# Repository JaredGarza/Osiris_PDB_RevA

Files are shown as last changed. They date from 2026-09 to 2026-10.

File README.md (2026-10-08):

# Osiris PDB REV1.1 XT60 prototype

Updated October 8, 2026. J1 battery input and J3 ESC output now use AMASS XT60PW-F, matching J4. Finished board is 82.5 x 65.0 mm. The four mounting holes and remaining circuit placements are retained. Open Osiris_PDB_RevA.kicad_pro; keep Libraries and the library tables alongside the project.

**XT60PW-F is rated 45 A, with 60 A momentary and no stated duration. The previous 60 A continuous / 100 A for 30 s targets are not supported by this connector. A 5 A avionics allowance leaves a 40 A connector-based ESC ceiling; revised PCB ampacity is unqualified. F2 remains 100 A and does not establish overload protection of the 45 A connector.**

Four layers, 1.6 mm FR-4, ENIG, retained low-copper prototype choice of 1 oz outer / 0.5 oz inner. DRC, schematic parity and ERC passed with zero reported issues. These checks establish CAD consistency, not thermal/current capability.

Latest manufacturing files: [outputs/jlcpcb-rev1.1](outputs/jlcpcb-rev1.1). Upload Gerbers.zip intact for PCB fabrication, BOM.csv for assembly parts, and Pick_and_Place.csv for assembly placement. This folder contains only those three files. Verify exact manufacturer part matches and orientations in the factory preview; LCSC selections remain unconfirmed. The procurement workbook and grouped live calculation inputs are in [engineering](engineering). Earlier output packages should not be used for this board. No order was submitted.

The former 2.07 mOhm screening estimate applies only to the old copper geometry. The revised layout needs new resistance extraction or four-wire measurements, thermal qualification, transient measurements and fuse/harness/connector coordination. Protection corrections: D5 SMBJ18CA, C17 330 uF / 50 V EEHZL1H331P; retry is C3=100 nF (550 ms), gate ramp is C1=22 nF. Host I2C1 pull-ups R74/R75 are 4.7 kOhm. Use the three-wire data harness described in [HOST_INTERFACE.md](HOST_INTERFACE.md). A tested portable INA228 driver is in Firmware, pending target integration and physical verification. See [PROTECTION_FIX_STATUS.md](PROTECTION_FIX_STATUS.md) for unresolved pack interruption/startup/SOA items and the engineering workbook for formulas and input assumptions.

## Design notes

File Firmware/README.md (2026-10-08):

# PDB INA228 driver

This driver targets the PDB INA228 at 0x40, using its 5 mOhm avionics-only shunt. It does not measure ESC or whole-pack current. It is suitable for integration into Osiris STM32H743 I2C1; host wiring and resistors are documented in the package's HOST_INTERFACE.md. It is not an entire flight-controller firmware image, and has not been flashed or tested on physical hardware.

Supply callbacks with a finite timeout. At an STM32 HAL boundary, shift the 7-bit address left once. Register data is MSB first. Use 100 kHz initially; do not automatically fall back to a different bus or INA228 address.

Initialize `pdb_ina228` with the context, callbacks and measured shunt resistance, or nominal 0.005 Ohm for initial bring-up. Call `pdb_ina228_init` after the PDB local rail is present. It validates manufacturer/device IDs, selects ADCRANGE=0, programs SHUNT_CAL=4096, selects 16 averages and 1052 us V/I/temperature conversion times, and checks readback. Nominal CURRENT_LSB is 62.5 uA/count, with a signed positive span one count below 32.768 A. The analog high range is also 32.768 A nominal; the low 8.192 A range is inappropriate for the possible 12.12 A breaker corner. Readback after power loss is mandatory.

Poll roughly every 100 ms. `pdb_ina228_sample` returns a status and a `valid` flag. Never use a failed/not-ready sample as a zero-current reading. Invalid values are NaN. The driver detects I/O failures, changed/reset configuration, memory faults, arithmetic overflow and clipping. It performs signed 20-bit conversion and uses the integer calibration to calculate the actual LSB. Check the sample age in the application, and publish communication faults separately from electrical current. Power/energy/charge accumulation and an interrupt-based alert path are not implemented. Sequential reads are not an atomic multi-register snapshot.

After a configuration-loss/I/O failure, mark telemetry unavailable and retry initialization with a bounded application retry policy. A firmware reboot alone does not constitute a battery disconnect. This driver has no authority over motor throttles or power switches and cannot make the 60/100 A target compatible with the XT60 connectors. Automatic disarming or propulsion interruption requires integration with the existing flight application's safety behavior.

The supplied C unit test was compiled with MSVC `/W4 /WX /std:c11`; it checks positive/negative readings, clipping, sensor fault flags, wrong device, configuration loss, I/O failure and invalid shunt inputs. Physical bring-up and integration remain required.

Source: Texas Instruments [INA228 datasheet](https://www.ti.com/lit/ds/symlink/ina228.pdf), register map and calibration equations. Nominal board identity and connections come from the current PDB netlist.

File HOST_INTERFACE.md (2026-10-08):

# PDB REV1.1 to Osiris Rev B

Verified from the current OsirisRevA schematic/netlist, October 8, 2026. Host is STM32H743IIK6 U10; use I2C1, PB8 (SCL) / PB9 (SDA), initially 100 kHz. The PDB INA228 address is **0x40 (7 bit)**. Osiris's onboard INA228 IC11 is a different device on I2C4, address 0x4F; do not apply this PDB's 5 mOhm calibration to IC11.

| PDB J2 | Cable connection | Osiris J28 |
|---|---|---|
| Pin 1: INA_ALERT, open-drain | **No connection; omit this conductor** | Pin 1 is +5V0_PROT; leave unused |
| Pin 2: SCL | Connect | Pin 2: FMU_I2C1_SCL |
| Pin 3: SDA | Connect | Pin 3: FMU_I2C1_SDA |
| Pin 4: GND | Connect | Pin 4: GND |

**A straight four-wire cable is incompatible.** It applies host 5 V to PDB ALERT. Use a three-conductor cable in the four-position keyed housings, with cavity 1 empty at both ends. Poll the PDB instead of using ALERT in this connection. Inspect cavity numbering against both board footprints and perform cable continuity checks before connection. No 5 V supply is carried in this data cable.

PDB R17/R18 remain DNP. Osiris I2C1 R74/R75 were changed in the current host schematic and PCB from 12 kOhm to **4.7 kOhm**, 0402, Yageo RC0402FR-074K7L. They connect to the host's switched +3V3 rail. No other host I2C bus resistors were changed. Host production outputs were not regenerated as part of the PDB package; use Osiris_Host_Pullup_Changes.csv when rebuilding its BOM. Check that no connected peripheral adds an excessive parallel pull-up.

For 4.7 kOhm and the historical 90 pF assumption, tr = 0.8473 R C = 358.4 ns. At 100 kHz, the 1000 ns rise-time criterion implies about 251 pF total capacitance, before resistor tolerance and design margin. At 400 kHz, the 300 ns criterion implies about 75 pF, so **do not switch this harness to 400 kHz based on the 90 pF estimate**. Measure SCL/SDA rise time, low voltage and ringing on the installed harness. Keep the ground conductor alongside the data conductors.

The PDB ALERT buffer is not used by this polling cable. Do not connect host power to it. Verify the host-off/PDB-on and PDB-off/host-on cases on the assembled system. The INA228 SCL/SDA absolute rating is independent of VS, unlike its ALERT rating; this alone does not qualify the entire powered-off bus.

Power cable: **PDB J4 pin 2 (+PDB_VOUT) -> Osiris J17 pin 1 (+VBATT_OUT); PDB J4 pin 1 GND -> Osiris J17 pin 2 GND**. This supplies protected, unregulated 4S battery voltage. Connector pin numbers differ; never connect by pin number alone.

Firmware source is provided in `source_snapshot/Firmware`. It is a transport-independent driver, not a flashed or integrated Osiris application. Configure the actual STM32 clock-dependent timing value through the existing firmware project and connect finite-timeout read/write callbacks to I2C1. No runnable firmware project was found in the local Hardware/Osiris repositories.

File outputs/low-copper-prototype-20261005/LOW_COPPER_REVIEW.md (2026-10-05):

# Osiris PDB REV1.1 — Low Copper Prototype

Prepared October 5, 2026 from the current Osiris_PDB_RevA project.

**Selected prototype specification: 1 oz outer / 0.5 oz inner, four-layer FR-4, 1.6 mm total thickness. This is the lowest standard copper combination listed by JLCPCB, not a demonstrated minimum for the board's current targets. The 60 A continuous / 100 A for 30 seconds targets remain unqualified.**

Open `Osiris_PDB_RevA.kicad_pro`. This branch keeps the repository's original project filenames, with the revised low-copper PCB in place. Keep the local Libraries folder and library tables beside the project. The schematic and component placement remain the same as the source design. The bottom silkscreen identifies this board as `LC TEST 1/0.5oz`.

The input and ESC positive pours were widened on the top and supplemented with parallel bottom pours. The sharp top-zone step near J3 was removed. In1 remains an uninterrupted ground-plane zone; In2 now carries ground in its unused left, lower and right regions rather than filling those regions with positive copper. Added 22 vias: five distributed ESC ties, fourteen return-path ties and three local capacitor/test-point ground ties. Three short ground tracks connect the latter pads to their new vias. Existing routed tracks, vias, footprint positions, pad geometry and part selections were preserved.

All-severity PCB DRC, unconnected-item checks, schematic parity and schematic ERC passed with zero reported issues. Thirteen Gerber/drill files were independently parsed, and exported copper artwork was visually reviewed. The Gerber job specifies 35 / 17.5 / 17.5 / 35 µm copper. The generic dielectric entries maintain nominal 1.6 mm thickness; use the manufacturer's standard compatible stackup rather than treating those entries as a controlled dielectric requirement.

## Quotation files

Use `outputs/low-copper-prototype-20261005/Osiris_PDB_REV1.1_LowCopper_Prototype_Gerbers.zip` for PCB upload. The same directory contains the unchanged BOM/CPL, assembly instructions, fabrication notes and checks; start with `START_HERE.md`. Earlier manufacturing packages retained in this repository describe the original board and must not be used for this revision. Select **1 oz outer and 0.5 oz inner explicitly** on the quote page; Gerber artwork alone does not establish copper weight. No order has been placed, and no savings amount has been verified.

## Resistance screening and test limits

A nominal room-temperature DC grid model compared the original and widened layouts. It includes positive paths and the ESC ground return, sheet-copper conductance and nominal 25 µm plated via barrels. It assumes ideal connector terminals and excludes fuse/contact/solder resistance, enclosure behavior and thermal coupling. Pads were simplified to rectangles/circles. This is a screening model, not a certified field solver or thermal simulation.

| Layout | Outer / inner | Estimated copper loop resistance | Estimated copper-only loss at 60 A |
|---|---|---:|---:|
| Original | 2 / 2 oz | 0.83 mΩ | 3.0 W |
| Widened | 2 / 1 oz | 1.06 mΩ | 3.8 W |
| Widened | 2 / 0.5 oz | 1.34 mΩ | 4.8 W |
| **Selected lowest-copper prototype** | **1 / 0.5 oz** | **2.07 mΩ** | **7.5 W** |

The selected prototype's estimated copper loop resistance is approximately **2.5 times the original** despite widening. Its approximate copper-only drop is 124 mV at 60 A. These figures do not include the fuse's substantial additional loss, and copper resistance increases with temperature. A preliminary 0.25 mm grid and the final 0.20 mm grid gave similar loop estimates, but that numerical agreement does not validate the model assumptions. Raw results are in `outputs/low-copper-prototype-20261005/checks/dc-screen-0.2.json`; that file records the geometry hashes.

Load/temperature measurements are required before accepting this copper choice for the current targets. Test both positive and ground drop, fuse/connector/via-region temperatures, and avionics behavior in the actual enclosure and ambient conditions. Input current can reach 65 A continuous or 105 A burst with a simultaneous 5 A avionics load; the model table above considers the 60 A ESC loop alone. Establish component-based temperature limits and measure steady-state behavior before attempting the target burst. If the lowest-copper prototype fails those requirements, use the measured results to select a heavier build or revise the layout further. This review cannot establish the lowest electrically adequate copper weight without those results.

Manufacturer copper options: [JLCPCB copper-weight guide](https://jlcpcb.com/help/article/jlcpcb-copper-weight). Current availability and price depend on the selected manufacturing/assembly service.

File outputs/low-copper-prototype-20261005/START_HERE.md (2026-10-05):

# Osiris PDB REV1.1 Low Copper — test prototype package

Upload **Osiris_PDB_REV1.1_LowCopper_Prototype_Gerbers.zip** for PCB quotation. Use **JLCPCB_BOM.csv** and **JLCPCB_CPL.csv** for assembly quotation.

Select four layers, FR-4, 1.6 mm, **1 oz outer / 0.5 oz inner**, ENIG and the requested quantity. Finished outline is 127.5 × 65 mm. Confirm the selected copper combination and assembly/panel requirements with JLCPCB.

This revised board has wider top copper, added bottom power pours, revised In2 ground return and 22 new vias. Its schematic, components, footprints and placement are unchanged. Do not upload the earlier RevA Gerbers with this package.

**TEST PROTOTYPE ONLY:** the lowest standard copper option was selected at the user's request. It is not qualified for 60 A continuous / 100 A for 30 seconds. Estimated copper-loop resistance is about 2.5 times the original 2/2 oz board. See LOW_COPPER_REVIEW.md for the estimate and physical testing still needed.

The BOM contains 56 fitted parts in 41 groups. Exact manufacturer/MPN matching and every polarity/orientation require checking in JLCPCB's assembly preview. F1 is the holder; the removable 7.5 A fuse is supplied separately. R17/R18 are DNP. No order has been placed.

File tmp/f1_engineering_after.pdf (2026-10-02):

D1 | 1 | SMAJ24CA | Bidirectional 400 W TVS; 24 V standoff, 26.7 V min
| | | breakdown, 38.9 V clamp | Diode_SMD:D_SMA | Bourns | SMAJ24CA

Bidirectional 24 V TVS candidate; 38.9 V specified clamp is pulsecondition dependent. Source energy, ringing and downstream peak
voltage remain open. | Open datasheet
D3 | 1 | STPST10H100SB | 100V 10A | PDB_Footprints:STPST10H100SB_DPAK | STMicroelectronics | STPST10H100SB-TR

Selected power clamp. Connect both anode leads to GND and cathode
tab to PDB_VOUT. Pulse/thermal validation required. | Open datasheet
D4 | 1 | SMAJ24CA | Bidirectional 400 W TVS; 24 V standoff, 26.7 V min
| | | breakdown, 38.9 V clamp | Diode_SMD:D_SMA | Bourns | SMAJ24CA

Selected: local bidirectional clamp from IDEAL_IN to U5 reference
IDEAL_VSS. | Open datasheet
D5 | 1 | SMBJ24CA

Bidirectional 24 V TVS candidate for local ESC
connector ringing control; validate pulse energy
and clamp voltage on the installed harness. | Diode_SMD:D_SMB | Littelfuse | SMBJ24CA

Procurement selection: Littelfuse SMBJ24CA. Retained for local ringing control; validate installed harness pulse energy and clamp behavior.

F1 | 1 | 7.5A MINI

7.5 A, 32 VDC MINI blade fuse; backup protection
for a fault the MOSFETs cannot interrupt | Fuse:Fuseholder_Blade_Mini_Keystone_3568 | Littelfuse | 029707.5WXNV | Keystone Electronics 3568 | Open datasheet

7.5 A 32 V MINI selected for 5 A continuous avionics allowance (67% of
fuse rating). Electronic breaker remains nominally 10 A; fuse, source | Open datasheet
F2 | 1 | SCHURTER UHS 100A 3- 140-178 | 100 A surface-mount high-current fuse candidate for the dedicated ESC branch

PDB_Footprints:SCHURTER_UHS_8.4x9.4mm_PR
OVISIONAL | SCHURTER | 3-140-178

PROCUREMENT UPDATE: use 3-140-178 in place of original 3-140-177. SCHURTER lists identical 100 A / 50 V UHS electrical ratings and package dimensions; order-number difference is packaging. DigiKey offers 3-140-
178 cut tape. Engineering release checks still apply: verify 60 A
continuous temperature rise, 100 A/30 s time-current behavior, 4S
pack fault current, breaking capacity, and heavy-copper land pattern. | Open datasheet
H1 | 0 | MountingHole | Mounting Hole without connection

MountingHole:MountingHole_3.2mm_M3_ISO1 4580

H2 | 0 | MountingHole | Mounting Hole without connection

MountingHole:MountingHole_3.2mm_M3_ISO1 4580

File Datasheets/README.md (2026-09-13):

# Component datasheets

Downloaded PDFs are stored beside this index. `origin` in `sources.json` records
whether a PDF came from the manufacturer or a distributor mirror; mirrors were used
where the manufacturer host returned HTTP 403. Entries still marked as unavailable
keep a manufacturer link in the schematic instead.

| Document | Local file / status | Source |
|---|---|---|
| AMASS_XT60PW-F.pdf | [AMASS_XT60PW-F.pdf](AMASS_XT60PW-F.pdf) | [Source](https://www.tme.eu/Document/1191bc2fa3aee3c446e5a895fd8f7983/XT60PW-F.pdf) |
| AMASS_XT60PW-M.pdf | [AMASS_XT60PW-M.pdf](AMASS_XT60PW-M.pdf) | [Source](https://www.tme.eu/Document/b13629717d44ae038681dba08d18c0b6/XT60PW-M.pdf) |
| Bourns_SMAJ_TVS.pdf | [Bourns_SMAJ_TVS.pdf](Bourns_SMAJ_TVS.pdf) | [Source](https://www.bourns.com/docs/product-datasheets/smaj.pdf) |
| INA228.pdf | [INA228.pdf](INA228.pdf) | [Source](https://www.ti.com/lit/ds/symlink/ina228.pdf) |
| JST_GH.pdf | [JST_GH.pdf](JST_GH.pdf) | [Source](https://www.jst-mfg.com/product/pdf/eng/eGH.pdf) |
| KEMET_C0603C104K4RACTU.pdf | [KEMET_C0603C104K4RACTU.pdf](KEMET_C0603C104K4RACTU.pdf) | [Source](https://search.kemet.com/component-documentation/download/specsheet/C0603C104K4RACTU) |
| Keystone_3568.pdf | [Keystone_3568.pdf](Keystone_3568.pdf) | [Source](https://www.keyelco.com/product-pdf.cfm?p=306) |
| Keystone_catalog.pdf | [Keystone_catalog.pdf](Keystone_catalog.pdf) | [Source](https://www.keystone-europe.com/wp-content/uploads/catalog-keystone-europe.pdf) |
| Littelfuse_297_MINI.pdf | [Littelfuse_297_MINI.pdf](Littelfuse_297_MINI.pdf) (mirror) | [Source](https://www.ficcorp.com/content/297-datasheet.pdf) |
| Littelfuse_MINI_0297.pdf | Superseded by Littelfuse_297_MINI.pdf | [Source](https://www.littelfuse.com/assetdocs/littelfuse_datasheet_297_mini32v.pdf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) |
| Littelfuse_MINI_0297_selection_guide.pdf | Superseded by Littelfuse_297_MINI.pdf | [Source](https://www.littelfuse.com/assetdocs/fuse-selection-guide?assetguid=1d99e3a6-f314-48d7-b124-9d5d56955f09) |
| Nexperia_74AUP1G07.pdf | [Nexperia_74AUP1G07.pdf](Nexperia_74AUP1G07.pdf) | [Source](https://assets.nexperia.com/documents/data-sheet/74AUP1G07.pdf) |
| Ohmite_FC4L.pdf | [Ohmite_FC4L.pdf](Ohmite_FC4L.pdf) (mirror) | [Source](https://www.tti.com/content/dam/ttiinc/manufacturers/ohmite/doc/ohmite-fc4l-series-current-sense-resistors-datasheet-and-specifications.pdf) |
| TDK_C1608X7R1H104K080AA.pdf | Online link; PDF download unavailable | [Source](https://product.tdk.com/info/en/documents/chara_sheet/C1608X7R1H104K080AA.pdf) |
| TDK_C2012C0G2A562J125AA.pdf | Online link; PDF download unavailable | [Source](https://product.tdk.com/info/en/documents/chara_sheet/C2012C0G2A562J125AA.pdf) |
| TDK_C2012X7R1A106K125AC.pdf | Online link; PDF download unavailable | [Source](https://product.tdk.com/info/en/documents/chara_sheet/C2012X7R1A106K125AC.pdf) |
| TDK_C2012X7R1H105K125AB.pdf | Online link; PDF download unavailable | [Source](https://product.tdk.com/info/en/documents/chara_sheet/C2012X7R1H105K125AB.pdf) |
| TDK_C3216X7R1H106K160AC.pdf | Online link; PDF download unavailable | [Source](https://product.tdk.com/info/en/documents/chara_sheet/C3216X7R1H106K160AC.pdf) |
| TPS7A16.pdf | [TPS7A16.pdf](TPS7A16.pdf) | [Source](https://www.ti.com/lit/ds/symlink/tps7a16.pdf) |
| onsemi_MBR0540.pdf | [onsemi_MBR0540.pdf](onsemi_MBR0540.pdf) (mirror) | [Source](https://cdn-reichelt.de/documents/datenblatt/A400/MBR0540T1-D.PDF) |

Existing project PDFs: [LTC4368](LTC4368%20%28Rev%20C%29.pdf) and [ISC015N06NM5LF2](Datasheet%20ISC015N06NM5LF2.pdf).

TDK links refer to characteristic sheets; the schematic retains manufacturer
product pages for each selected capacitor.

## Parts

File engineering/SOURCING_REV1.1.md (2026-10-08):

# REV1.1 procurement substitutions

Checked October 8, 2026. Updated 14 fitted components across 11 MPN groups. Values, packages, copper routing and board size are unchanged. Resistors are 0805, 1%, 125 mW, 150 V; 10 ohm parts have 200 ppm/K TCR and the others 100 ppm/K. Capacitors are 0805, X7R, 50 V, 10%. Stock is a reported snapshot, not a guarantee of future availability or JLC assembly stock. Confirm exact parts at order time.

| References | Selected MPN | LCSC | Reported stock |
|---|---|---|---:|
| C2,C18 | CC0805KKX7R9BB105 | [C91185](https://www.lcsc.com/product-detail/C91185.html) | 767,960 |
| C19 | CC0805KRX7R9BB104 | [C49678](https://www.lcsc.com/product-detail/C49678.html) | 8,362,320 |
| R3 | 0805W8F2004T5E | [C26112](https://www.lcsc.com/product-detail/C26112.html) | 17,200 |
| R4 | 0805W8F2202T5E | [C17560](https://www.lcsc.com/product-detail/C17560.html) | 1,226,000 |
| R6 | 0805W8F6803T5E | [C17797](https://www.lcsc.com/product-detail/C17797.html) | 64,300 |
| R7 | 0805W8F2003T5E | [C17539](https://www.lcsc.com/product-detail/C17539.html) | 428,200 |
| R8,R9 | 0805W8F100JT5E | [C17415](https://www.lcsc.com/product-detail/C17415.html) | 4,712,400 |
| R10 | 0805W8F4701T5E | [C17673](https://www.lcsc.com/product-detail/C17673.html) | 1,678,600 |
| R12 | 0805W8F1001T5E | [C17513](https://www.lcsc.com/product-detail/C17513.html) | 24,259,800 |
| R15,R16 | 0805W8F1002T5E | [C17414](https://www.lcsc.com/product-detail/C17414.html) | 48,598,900 |
| R21 | 0805W8F1000T5E | [C17408](https://www.lcsc.com/product-detail/C17408.html) | 6,871,100 |

C17 remains Panasonic EEHZL1H331P: 330 µF, 50 V, 12 mΩ at 100 kHz and 5 A ripple at 125 °C. No verified single-part replacement was found meeting capacitance, voltage, ESR, ripple current and the G16 package. EEH-ZU1H221P is only 220 µF and is not an approved direct replacement. Two parallel parts would require a separate layout and transient validation.

Retained the linear-mode MOSFETs, protection ICs, INA228, Kelvin shunt, high-power resistors, fuses and film capacitors because a sourcing swap must preserve their specific electrical function. Existing KEMET 0603 decouplers already have deep reported stock; the investigated Samsung option had much less reported stock. Precision divider values were retained.

Fresh KiCad DRC: zero violations, zero unconnected items, zero schematic parity issues. ERC: zero violations. Calculation inputs and formulas are unchanged. These CAD checks do not establish hardware transient or thermal qualification.

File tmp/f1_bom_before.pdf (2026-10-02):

Boards to build | 5 | Estimated cost / board
Category | References | Value / Part | Manufacturer
Capacitor | C1 | 22n | TDK
Capacitor | C2 | 1U0 | TDK
Capacitor | C3, C5, C8, C10 | 100n | KEMET
Capacitor | C4, C9 | 10u | TDK
Capacitor | C6 | 10u | TDK
Capacitor | C7 | 100n | TDK
Capacitor | C11, C12, C13, C14, C15, C16 1u | TDK
Capacitor | C17 | 470u 35V HYBRID | Panasonic
Capacitor | C18 | 1u 50V X7R | KYOCERA AVX
Capacitor | C19 | 100n 50V X7R | KEMET
Diode / TVS | D1, D4 | SMAJ24CA | Bourns
Diode / TVS | D3 | STPST10H100SB | STMicroelectronics
Diode / TVS | D5 | SMBJ24CA | Littelfuse
Fuse | F1 | 4A MINI | Littelfuse
Fuse | F2 | SCHURTER UHS 100A 3-140-
| | 178 | SCHURTER
Connector | J1, J3 | MKDSP 25/2-15.00
| | PROVISIONAL | Phoenix Contact
Connector | J2 | OSIRIS_I2C | JST

## Osiris PDB Rev A — Purchasing BOM (links corrected)

Updated from the Oct. 1, 2026 KiCad design and purchasing sheet. Existing priced rows remain legacy budget values unless marked otherwise; shipping/tax/assembly excluded.

Connector | J4 | XT60PW-F | AMASS
MOSFET | Q1, Q2 | ISC015N06NM5LF2 | Infineon
MOSFET | Q3 | BSC070N10NS5 | Infineon
Resistor | R1 | 237k | YAGEO
Resistor | R2 | 11k8 | YAGEO
Resistor | R3 | 2M0 | YAGEO
Resistor | R4 | 22k | YAGEO
Resistor | R5 | 5m | Ohmite
Resistor | R6 | 680k | YAGEO
Resistor | R7 | 200k | YAGEO
Resistor | R8, R9 | 10 | YAGEO
Resistor | R10, R17 (DNP), R18 (DNP) | 4k7 | YAGEO
Resistor | R11 | 1k58 | YAGEO
Resistor | R12 | 1k0 | YAGEO
Resistor | R13 | 54k9 | YAGEO
Resistor | R14 | 22M | YAGEO
Resistor | R15, R16 | 10k | YAGEO
Resistor | R19 | 1k | Vishay
Resistor | R20 | 1 | Vishay
Resistor | R21 | 100 | Yageo
IC | U1 | LTC4368HMS-1-PBF | Analog Devices

IC | U2 | INA228AIDGSR | Texas Instruments
IC | U3 | LT3010EMS8E | Analog Devices
IC | U4 | 74AUP1G07GW | Nexperia
IC | U5 | LTC4359IMS8 | Analog Devices
Fuse Holder | F1-holder | MINI fuse holder | Keystone Electronics
ESTIMATED TOTAL (all unit prices filled; F2 currently stock-blocked)

87.2124 Estimated batch cost 436.062

Manufacturer P/N | Qty / Board Board Count (X) | Total Qty | Unit Cost (USD)
C2012C0G2A223J125AC | 1 | 5 | 5 | $0.30
C2012X7R1H105K125AB | 1 | 5 | 5 | $0.26
C0603C104K4RACTU | 4 | 5 | 20 | $0.13
C3216X7R1H106K160AC | 2 | 5 | 10 | $0.98
C2012X7R1A106K125AC | 1 | 5 | 5 | $0.33
C1608X7R1H104K080AA | 1 | 5 | 5 | $0.10
B32529C0105J189 | 6 | 5 | 30 | $0.30
EEH-ZS1V471P | 1 | 5 | 5 | $2.78
08055C105KAT2A | 1 | 5 | 5 | $0.27
C0805C104K5RACTU | 1 | 5 | 5 | $0.18
SMAJ24CA | 2 | 5 | 10 | $0.53
STPST10H100SB-TR | 1 | 5 | 5 | $1.44
SMBJ24CA | 1 | 5 | 5 | $0.57
0297004.WXNV | 1 | 5 | 5 | $0.39
3-140-178 | 1 | 5 | 5 | $1.07
1932588 | 2 | 5 | 10 | $13.01
BM04B-GHS-TBT(LF)(SN) | 1 | 5 | 5 | $0.38

XT60PW-F | 1 | 5 | 5 | $0.65
ISC015N06NM5LF2ATMA1 | 2 | 5 | 10 | $4.07
BSC070N10NS5ATMA1 | 1 | 5 | 5 | $2.24
RC0805FR-07237KL | 1 | 5 | 5 | $0.10
RC0805FR-0711K8L | 1 | 5 | 5 | $0.10
RC0805FR-072ML | 1 | 5 | 5 | $0.10
RC0805FR-0722KL | 1 | 5 | 5 | $0.10
FC4L64R005FER | 1 | 5 | 5 | $2.69
RC0805FR-07680KL | 1 | 5 | 5 | $0.10
RC0805FR-07200KL | 1 | 5 | 5 | $0.10
RC0805FR-0710RL | 2 | 5 | 10 | $0.12
RC0805FR-074K7L | 1 | 5 | 5 | $0.10
RC0805FR-071K58L | 1 | 5 | 5 | $0.10
RC0805FR-071KL | 1 | 5 | 5 | $0.10
RC0805FR-0754K9L | 1 | 5 | 5 | $0.10
RC0805JR-0722ML | 1 | 5 | 5 | $0.16
RC0805FR-0710KL | 2 | 5 | 10 | $0.10
CRCW25121K00FKEGHP | 1 | 5 | 5 | $0.75
CRCW25121R00FKEGHP | 1 | 5 | 5 | $0.96
RC0805FR-07100RL | 1 | 5 | 5 | $0.10
LTC4368HMS-1#TRPBF | 1 | 5 | 5 | $9.32

INA228AIDGSR

1

5

5 | $4.68

LT3010EMS8E#TRPBF

1

5

5 | $6.45

74AUP1G07GW,125

1

5

5 | $0.19

LTC4359IMS8#TRPBF

1

5

5 | $8.72

3568

1

5

5 | $1.31

Availability blockers | 0 | Resolved link/MPN gaps
Cost / Board | Total Cost | Distributor | Buy Link
$0.30 | $1.50 DigiKey | Supplier page
$0.26 | $1.30 DigiKey | Supplier page
$0.52 | $2.60 DigiKey | Supplier page
$1.96 | $9.80 DigiKey | Supplier page
$0.33 | $1.65 DigiKey | Supplier page
$0.10 | $0.50 DigiKey | Supplier page
$1.78 | $8.91 Mouser | Buy
$2.78 | $13.90 DigiKey | Buy
$0.27 | $1.35 DigiKey | Buy
$0.18 | $0.90 DigiKey | Buy
$1.06 | $5.30 Mouser | Supplier page
$1.44 | $7.20 DigiKey | Buy
$0.57 | $2.85 DigiKey | Buy
$0.39 | $1.95 Mouser | Supplier page
$1.07 | $5.37 DigiKey | Buy
$26.02 | $130.10 Mouser | Buy
$0.38 | $1.90 Mouser | Supplier page

$0.65 | $3.23 LCSC | Buy
$8.14 | $40.70 DigiKey | Supplier page
$2.24 | $11.20 Mouser | Buy
$0.10 | $0.50 DigiKey | Supplier page
$0.10 | $0.50 DigiKey | Supplier page
$0.10 | $0.50 Mouser | Supplier page
$0.10 | $0.50 DigiKey | Supplier page
$2.69 | $13.45 Mouser | Supplier page
$0.10 | $0.50 Mouser | Supplier page
$0.10 | $0.50 Mouser | Supplier page
$0.24 | $1.20 DigiKey | Supplier page
$0.10 | $0.50 DigiKey | Supplier page
$0.10 | $0.50 DigiKey | Supplier page
$0.10 | $0.50 DigiKey | Supplier page
$0.10 | $0.50 DigiKey | Supplier page
$0.16 | $0.80 DigiKey | Supplier page
$0.20 | $1.00 DigiKey | Supplier page
$0.75 | $3.75 Mouser | Buy
$0.96 | $4.80 DigiKey | Buy
$0.10 | $0.50 DigiKey | Buy
$9.32 | $46.60 Mouser | Buy

$4.68 | $23.40 DigiKey | Supplier page
$6.45 | $32.25 DigiKey | Supplier page
$0.19 | $0.95 DigiKey | Supplier page
$8.72 | $43.60 Mouser | Buy
$1.31 | $6.55 DigiKey | Supplier page
$87.21 | $436.06

15

Source URL

https://www.digikey.com/en/products/detail/tdkcorporation/C2012C0G2A223J125AC/5023347https://www.digikey.com/en/products/detail/tdk/C2012X7R1H105K125AB/2732982
https://www.digikey.com/en/products/detail/kemet/C0603C104K4RACTU/411095
https://www.digikey.com/en/products/detail/tdk/C3216X7R1H106K160AC/9991386
https://www.digikey.com/en/products/detail/tdkcorporation/C2012X7R1A106K125AC/2619198https://www.digikey.com/en/products/detail/tdk/C1608X7R1H104K080AA/513811
https://www.mouser.com/ProductDetail/TDK/B32529C0105J189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
https://www.mouser.com/en/ProductDetail/Bourns/SMAJ24CA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

https://www.mouser.com/ProductDetail/Littelfuse/0297004.WXNV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
https://www.mouser.com/en/ProductDetail/Phoenix-Contact/1932588?qs=zGjMOL9s0Z%252BnZxcpLOCAEA %3D%3D
https://www.mouser.com/ProductDetail/JST-Commercial/BM04B-GHS-TBTLFSNhttps://lcsc.com/product-detail/plug_changzhou-amasselec-xt60pw-f_C428722.htmlhttps://www.digike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

https://www.mouser.com/en/ProductDetail/Infineon-Technologies/BSC070N10NS5ATMA1?qs=3Bi3m9r5MQY NTOsczKwccQ%3D%3D
https://www.digikey.com/en/products/detail/yageo/RC0805FR-07237KL/727754
https://www.digikey.com/en/products/detail/yageo/RC0805FR-0711K8L/730505
https://www.mouser.com/ProductDetail/YAGEO/RC080 5FR-072ML
https://www.digikey.com/en/products/detail/yageo/RC0805FR-0722KL/730683
https://www.mouser.com/ProductDetail/Ohmite/FC4L6 4R005FER
https://www.mouser.com/ProductDetail/YAGEO/RC080 5FR-07680KL
https://www.mouser.com/en/ProductDetail/YAGEO/RC 0805FR-07200KL
https://www.digikey.com/en/products/detail/yageo/RC0805FR-0710RL/730481
https://www.digikey.com/en/products/detail/yageo/RC0805FR-074K7L/727929
https://www.digikey.com/en/products/detail/yageo/RC0805FR-071K58L/730449
https://www.digikey.com/en/products/detail/yageo/RC0805FR-071KL/727444
https://www.digikey.com/en/products/detail/yageo/RC0805FR-0754K9L/728029
https://www.digikey.com/en/products/detail/yageo/RC0805JR-0722ML/5919060
https://www.digikey.com/en/products/detail/yageo/RC0805FR-0710KL/727535
https://www.mouser.com/en/ProductDetail/Vishay/CRCW25121K00FKEGHP?qs=FlFvgi4rxBxxON%252BaL1o0tw %3D%3D
https://www.digikey.com/en/products/detail/vishaydale/CRCW25121R00FKEGHP/2222582https://www.digikey.com/en/products/detail/yageo/RC0805FR-07100RL/727543
https://www.mouser.com/ProductDetail/Analog-Devices/LTC4368HMS-1TRPBF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 BvsYg%3D%3D
https://www.digikey.com/en/products/detail/keystoneelectronics/3568/2137306

Reference | Quantity | Value | Specification
C1 | 1 | 22n | 100V C0G 5%
C2 | 1 | 1U0 | 50V X7R
C3 | 1 | 100n | 16V X7R
C4 | 1 | 10u | 50V X7R
C5 | 1 | 100n | 16V X7R
C6 | 1 | 10u | 10V X7R
C7 | 1 | 100n | 50V X7R
C8 | 1 | 100n | 16V X7R
C9 | 1 | 10u | 50V X7R
C10 | 1 | 100n | 16V X7R; LT3010 feedback compensation
C11 | 1 | 1u | 63V film 5%
C12 | 1 | 1u | 63V film 5%
C13 | 1 | 1u | 63V film 5%
C14 | 1 | 1u | 63V film 5%
C15 | 1 | 1u | 63V film 5%
C16 | 1 | 1u | 63V film 5%

## Osiris PDB Rev A — Engineering BOM Detail

Cross-checked against the uploaded current KiCad schematic. C17 and R19 metadata were stale in the purchasing workbook; C18/C19/D5 procurement selections are recorded here.

C17 | 1 | 470u 35V HYBRID | Local supplemental ESC capacitor: 470 uF, 35 V hybrid, 11 mOhm ESR at 100 kHz, 4 Arms at 100 kHz/125 C. Preserve the ESC manufacturer-required capacitor at the ESC.
C18 | 1 | 1u 50V X7R | 50 V X7R ceramic bypass for the ESC branch
C19 | 1 | 100n 50V X7R | 50 V X7R high-frequency bypass for the ESC branch
D1 | 1 | SMAJ24CA | Bidirectional 400 W TVS; 24 V standoff, 26.7 V min breakdown, 38.9 V clamp
D3 | 1 | STPST10H100SB | 100V 10A
D4 | 1 | SMAJ24CA | Bidirectional 400 W TVS; 24 V standoff, 26.7 V min breakdown, 38.9 V clamp
D5 | 1 | SMBJ24CA

Bidirectional 24 V TVS candidate for local ESC connector ringing control; validate pulse energy and clamp voltage on the installed harness.

F1 | 1 | 4A MINI

4 A, 32 VDC MINI blade fuse; backup protection for a fault the MOSFETs cannot interrupt

F2 | 1 | SCHURTER UHS 100A 3- 140-178 | 100 A surface-mount high-current fuse candidate for the dedicated ESC branch
H1 | 0 | MountingHole | Mounting Hole without connection
H2 | 0 | MountingHole | Mounting Hole without connection
H3 | 0 | MountingHole | Mounting Hole without connection
H4 | 0 | MountingHole | Mounting Hole without connection
J1 | 1

MKDSP 25/2-15.00
PROVISIONAL

4S battery input; pin 1 GND, pin 2 VBAT_RAW. Phoenix Contact 1932588 terminal; footprint and assembly require verification.

J2 | 1 | OSIRIS_I2C

JST GH 4-way I2C: 1 NC, 2 SCL, 3 SDA, 4 GND. New Osiris interface and cable continuity require verification.

J3 | 1

MKDSP 25/2-15.00
PROVISIONAL

Dedicated ESC output after F2; pin 1 GND, pin 2 ESC_VBAT. Phoenix Contact 1932588 terminal; footprint and assembly require verification.

J4 | 1 | XT60PW-F

Avionics raw-4S output to Osiris: pin 1 GND, pin 2 PDB_VOUT. This connector remains on the protected 4 A avionics branch.

Q1 | 1 | ISC015N06NM5LF2

Insulated-Gate Field-Effect Transistor (IGFET), N-Channel, Enhancement, Body Diode, Pin 1 Source, 2 Source, 3 Source, 4 Gate, 5 Drain, 6 Drain, 7 Drain, 8 Drain, 8 Pins
Q2 | 1 | ISC015N06NM5LF2 | Insulated-Gate Field-Effect Transistor (IGFET), N-
| | | Channel, Enhancement, Body Diode, Pin 1 Source, 2
| | | Source, 3 Source, 4 Gate, 5 Drain, 6 Drain, 7 Drain,
| | | 8 Drain, 8 Pins
Q3 | 1 | BSC070N10NS5 | 100V ideal diode MOSFET
R1 | 1 | 237k | Resistor
R2 | 1 | 11k8 | Resistor
R3 | 1 | 2M0 | Resistor
R4 | 1 | 22k | Series resistor in gate-to-ground timing branch
R5 | 1 | 5m | 1% 2W
R6 | 1 | 680k | Resistor
R7 | 1 | 200k | Resistor
R8 | 1 | 10 | Resistor
R9 | 1 | 10 | Resistor
R10 | 1 | 4k7 | Resistor
R11 | 1 | 1k58 | 1% 0.125W; upper feedback resistor
R12 | 1 | 1k0 | 1% 0.125W; lower feedback resistor
R13 | 1 | 54k9 | Resistor
R14 | 1 | 22M | Resistor
R15 | 1 | 10k | Resistor
R16 | 1 | 10k | Resistor
R17 | 0 | 4k7 | Optional SCL pull-up; do not populate
R18 | 0 | 4k7 | Optional SDA pull-up; do not populate
R19 | 1 | 1k | Pulse-rated
R20 | 1 | 1 | Pulse-rated
R21 | 1 | 100 | 1%
TP1 | 0 | TestPoint | test point
TP2 | 0 | TestPoint | test point
TP3 | 0 | TestPoint | test point

TP4 | 0 | TestPoint | test point
TP5 | 0 | TestPoint | test point
TP6 | 0 | TestPoint | test point
TP7 | 0 | TestPoint | test point
U1 | 1 | LTC4368HMS-1-PBF

Approved H-temperature-grade LTC4368-1; pin/function-compatible with LTC4368IMS-1 and rated -40 C to 125 C
U2 | 1 | INA228AIDGSR
U3 | 1 | LT3010EMS8E | Reverse-protected local 3.3 V supply
U4 | 1 | 74AUP1G07GW | Single Buffer Gate, Open Drain, Low-Voltage CMOS
U5 | 1 | LTC4359IMS8 | Reverse-current blocker
F1-holder | 1 | MINI fuse holder | Separate purchased holder for F1

Footprint | Manufacturer | MPN
Capacitor_SMD:C_0805_2012Metric | TDK | C2012C0G2A223J125AC
Capacitor_SMD:C_0805_2012Metric | TDK | C2012X7R1H105K125AB
Capacitor_SMD:C_0603_1608Metric | KEMET | C0603C104K4RACTU
Capacitor_SMD:C_1206_3216Metric | TDK | C3216X7R1H106K160AC
Capacitor_SMD:C_0603_1608Metric | KEMET | C0603C104K4RACTU
Capacitor_SMD:C_0805_2012Metric | TDK | C2012X7R1A106K125AC
Capacitor_SMD:C_0603_1608Metric | TDK | C1608X7R1H104K080AA
Capacitor_SMD:C_0603_1608Metric | KEMET | C0603C104K4RACTU
Capacitor_SMD:C_1206_3216Metric | TDK | C3216X7R1H106K160AC
Capacitor_SMD:C_0603_1608Metric | KEMET | C0603C104K4RACTU

Capacitor_THT:C_Rect_L7.2mm_W4.5mm_P5.00
mm | TDK | B32529C0105J189

Capacitor_THT:C_Rect_L7.2mm_W4.5mm_P5.00
mm | TDK | B32529C0105J189

Capacitor_THT:C_Rect_L7.2mm_W4.5mm_P5.00
mm | TDK | B32529C0105J189

Capacitor_THT:C_Rect_L7.2mm_W4.5mm_P5.00
mm | TDK | B32529C0105J189

Capacitor_THT:C_Rect_L7.2mm_W4.5mm_P5.00
mm | TDK | B32529C0105J189

Capacitor_THT:C_Rect_L7.2mm_W4.5mm_P5.00
mm | TDK | B32529C0105J189

PDB_Footprints:CP_Elec_Panasonic_G16_10x16.
5 | Panasonic | EEH-ZS1V471P
Capacitor_SMD:C_0805_2012Metric | KYOCERA AVX | 08055C105KAT2A
Capacitor_SMD:C_0805_2012Metric | KEMET | C0805C104K5RACTU
Diode_SMD:D_SMA | Bourns | SMAJ24CA
PDB_Footprints:STPST10H100SB_DPAK | STMicroelectronics | STPST10H100SB-TR
Diode_SMD:D_SMA | Bourns | SMAJ24CA
Diode_SMD:D_SMB | Littelfuse | SMBJ24CA
Fuse:Fuseholder_Blade_Mini_Keystone_3568 | Littelfuse | 0297004.WXNV

PDB_Footprints:SCHURTER_UHS_8.4x9.4mm_PR
OVISIONAL | SCHURTER | 3-140-178
MountingHole:MountingHole_3.2mm_M3_ISO1
4580
MountingHole:MountingHole_3.2mm_M3_ISO1
4580
MountingHole:MountingHole_3.2mm_M3_ISO1 4580
MountingHole:MountingHole_3.2mm_M3_ISO1 4580

PDB_Footprints:MKDSP25_2_15mm_PROVISION
AL | Phoenix Contact | 1932588

Connector_JST:JST_GH_BM04B-GHS-TBT_1x04-
1MP_P1.25mm_Vertical | JST | BM04B-GHS-TBT(LF)(SN)

PDB_Footprints:MKDSP25_2_15mm_PROVISION
AL | Phoenix Contact | 1932588

Connector_AMASS:AMASS_XT60PW-
F_1x02_P7.20mm_Horizontal | AMASS | XT60PW-F

PDB_Footprints:ISC015N06NM5LF2_TDSON8FL Infineon | ISC015N06NM5LF2ATMA1
PDB_Footprints:ISC015N06NM5LF2_TDSON8FL Infineon | ISC015N06NM5LF2ATMA1
PDB_Footprints:BSC070N10NS5_TDSON8 | Infineon | BSC070N10NS5ATMA1
Resistor_SMD:R_0805_2012Metric | YAGEO | RC0805FR-07237KL
Resistor_SMD:R_0805_2012Metric | YAGEO | RC0805FR-0711K8L
Resistor_SMD:R_0805_2012Metric | YAGEO | RC0805FR-072ML
Resistor_SMD:R_0805_2012Metric | YAGEO | RC0805FR-0722KL
PDB_Footprints:OH_FC4L64_OHM | Ohmite | FC4L64R005FER
Resistor_SMD:R_0805_2012Metric | YAGEO | RC0805FR-07680KL
Resistor_SMD:R_0805_2012Metric | YAGEO | RC0805FR-07200KL
Resistor_SMD:R_0805_2012Metric | YAGEO | RC0805FR-0710RL
Resistor_SMD:R_0805_2012Metric | YAGEO | RC0805FR-0710RL
Resistor_SMD:R_0805_2012Metric | YAGEO | RC0805FR-074K7L
Resistor_SMD:R_0805_2012Metric | YAGEO | RC0805FR-071K58L
Resistor_SMD:R_0805_2012Metric | YAGEO | RC0805FR-071KL
Resistor_SMD:R_0805_2012Metric | YAGEO | RC0805FR-0754K9L
Resistor_SMD:R_0805_2012Metric | YAGEO | RC0805JR-0722ML
Resistor_SMD:R_0805_2012Metric | YAGEO | RC0805FR-0710KL
Resistor_SMD:R_0805_2012Metric | YAGEO | RC0805FR-0710KL
Resistor_SMD:R_0805_2012Metric | YAGEO | RC0805FR-074K7L
Resistor_SMD:R_0805_2012Metric | YAGEO | RC0805FR-074K7L
Resistor_SMD:R_2512_6332Metric | Vishay | CRCW25121K00FKEGHP
Resistor_SMD:R_2512_6332Metric | Vishay | CRCW25121R00FKEGHP
Resistor_SMD:R_0805_2012Metric | Yageo | RC0805FR-07100RL
TestPoint:TestPoint_Pad_D1.5mm
TestPoint:TestPoint_Pad_D1.5mm
TestPoint:TestPoint_Pad_D1.5mm

TestPoint:TestPoint_Pad_D1.5mm TestPoint:TestPoint_Pad_D1.5mm TestPoint:TestPoint_Pad_D1.5mm TestPoint:TestPoint_Pad_D1.5mm

PDB_Footprints:MS_10-MSOP_ADI | Analog Devices | LTC4368HMS-1#TRPBF
PDB_Footprints:VSSOP10_DGS_TEX | Texas Instruments | INA228AIDGSR

Package_SO:MSOP-8-
1EP_3x3mm_P0.65mm_EP1.68x1.88mm | Analog Devices | LT3010EMS8E#TRPBF
Package_TO_SOT_SMD:SOT-353_SC-70-5 | Nexperia | 74AUP1G07GW,125
Package_SO:MSOP-8_3x3mm_P0.65mm | Analog Devices | LTC4359IMS8#TRPBF
Fuse:Fuseholder_Blade_Mini_Keystone_3568 | Keystone Electronics 3568

Holder Manufacturer | Holder MPN | Holder Datasheet

Keystone Electronics 3568 | Open datasheet

Selection Status | Datasheet

22 nF 5% C0G in series with R4 from GATE_PIN to GND. PDB-only
candidate; original Osiris eFuse configuration retained. | Open datasheet
Nominal specification verified; DC-bias and circuit validation pending | Open datasheet
Nominal specification verified; DC-bias and circuit validation pending | Open datasheet
10 uF local U3 input capacitor on protected PDB_VOUT. | Open datasheet
Nominal specification verified; DC-bias and circuit validation pending | Open datasheet
A-P2 LT3010 output capacitor: require >=1 uF effective over
bias/temperature and ESR <=3 ohms. Confirm manufacturer bias curve
and assembled stability. | Open datasheet
Nominal specification verified; DC-bias and circuit validation pending | Open datasheet
Nominal specification verified; DC-bias and circuit validation pending | Open datasheet
Output bulk capacitor; final total downstream capacitance and startup
load must meet the proposed September 15 envelope. Inrush not
qualified. | Open datasheet
A-P2 U3 feedback network; layout and assembled transient verification
required. | Open datasheet

Selected: 1 uF 63 V 5% polyester film. SPICE uses 0.9 uF minimum
effective capacitance; verify mounted pulse and temperature behavior. Open datasheet

Selected: 1 uF 63 V 5% polyester film. SPICE uses 0.9 uF minimum
effective capacitance; verify mounted pulse and temperature behavior. Open datasheet

Selected: 1 uF 63 V 5% polyester film. SPICE uses 0.9 uF minimum
effective capacitance; verify mounted pulse and temperature behavior. Open datasheet

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

Selected EEH-ZS1V471P G16; 10 mm diameter, 16.5/16.8 mm class height. Additional ESC-side capacitor and harness transient/ripple tests required.
Procurement selection: 1 uF 50 V X7R 0805, active/stocked; verify effective capacitance under DC bias in final ESC branch.
Procurement selection: 100 nF 50 V X7R 0805, active/stocked; local high-frequency ESC bypass.
Bidirectional 24 V TVS candidate; 38.9 V specified clamp is pulsecondition dependent. Source energy, ringing and downstream peak
voltage remain open. | Open datasheet
Selected power clamp. Connect both anode leads to GND and cathode
tab to PDB_VOUT. Pulse/thermal validation required. | Open datasheet
Selected: local bidirectional clamp from IDEAL_IN to U5 reference
IDEAL_VSS. | Open datasheet

Procurement selection: Littelfuse SMBJ24CA. Retained for local ringing
control; validate installed harness pulse energy and clamp behavior.
4 A 32 V MINI; load envelope 2.5 A maximum. Fuse, source and
conductor coordination remains a release requirement. | Open datasheet

PROCUREMENT UPDATE: use 3-140-178 in place of original 3-140-177.
SCHURTER lists identical 100 A / 50 V UHS electrical ratings and package
dimensions; order-number difference is packaging. DigiKey offers 3-140-
178 cut tape. Engineering release checks still apply: verify 60 A
continuous temperature rise, 100 A/30 s time-current behavior, 4S pack
fault current, breaking capacity, and heavy-copper land pattern. | Open datasheet

LAB DESIGN IN PROGRESS: verify exact terminal, footprint, conductor,
wave-solder process, and power-path temperature before full-current
use. | Open datasheet
PDB pinout fixed; Osiris R74/R75 12k pull-ups to switched 3.3 V; 100
kHz, <=90 pF total bus capacitance. No power on pin 1. Physical cable
mating and new Rev B mapping unverified. | Open datasheet
LAB DESIGN IN PROGRESS: verify exact terminal, footprint, conductor,
wave-solder process, and power-path temperature before full-current
use. | Open datasheet

PDB polarity fixed. Verify physical cable contacts and board-edge
clearance; old Osiris J16 numbering is not the new Rev B interface. Open datasheet

Open datasheet

Open datasheet
Selected: 100 V low-charge MOSFET. Source IDEAL_IN, drain
VBAT_FUSED, gate IDEAL_GATE. | Open datasheet
1% 0805 UV divider. Selected for cold-start threshold margin at 12 V;
see A-P3 calculation report. | Open datasheet
1% 0805; lower UV divider resistor. | Open datasheet
Package assigned; MPN and power/tolerance validation pending | Open datasheet
U1 GATE directly drives Q1/Q2. R4 is in series with C1 to ground, per
LTC4368 Figure 7.
5 mOhm 1% 2 W four-terminal. Nominal breaker 10 A; normalcondition range 7.92-12.12 A. F1 remains 4 A; conductor/fuse
coordination required. | Open datasheet
Package assigned; MPN and power/tolerance validation pending
Package assigned; MPN and power/tolerance validation pending
Package assigned; MPN and power/tolerance validation pending
Package assigned; MPN and power/tolerance validation pending
Package assigned; MPN and power/tolerance validation pending
A-P2 U3 feedback network; layout and assembled transient verification
required. | Open datasheet
A-P2 U3 feedback network; layout and assembled transient verification
required. | Open datasheet
Rev-B candidate; MPN pending distributor check | Open datasheet
22 MOhm 5% gate feedback. Manufacturer order code verified;
tolerance included in divider calculation. | Open datasheet
Rev-B candidate; MPN pending distributor check
Rev-B candidate; MPN pending distributor check
DNP: host owns pull-up to its switched 3.3 V rail. No local pull-up is
allowed with an independently powered host.
DNP: host owns pull-up to its switched 3.3 V rail. No local pull-up is allowed with an independently powered host.

Selected: 1k 1% CRCW-HP 2512 reference return. MPN corrected from CRCW25121001FKEGHP to CRCW25121K00FKEGHP. Keep close to U5. Open datasheet Selected: 1 ohm 1% CRCW-HP 2512 input damping. Verify pulse energy
in layout/bench tests. | Open datasheet
Selected: VBUS filter with C14. Allow 1 ms settling before valid
measurements. | Open datasheet
Bare copper test pad; no fitted part required
Bare copper test pad; no fitted part required
Bare copper test pad; no fitted part required

Bare copper test pad; no fitted part required Bare copper test pad; no fitted part required Bare copper test pad; no fitted part required Bare copper test pad; no fitted part required

Open datasheet
Open datasheet
A-P2 engineering draft: reverse-input/current-protected LT3010;
R11/R12/C10 set nominal 3.29 V. Verify startup, effective C6 and
assembled rail transients. | Open datasheet
| Open datasheet
Selected: LTC4359 100 V ideal-diode controller; SHDN tied to IN. VSS
return uses R19. | Open datasheet
Holder qualification pending | Open datasheet

BOM Role

Schematic component

Schematic component

Schematic component
Schematic component

Schematic component

Schematic component

Schematic component

Schematic component

Schematic component

Schematic component

Schematic component

Schematic component

Schematic component

Schematic component

Schematic component

Schematic component

Schematic component

Schematic component

Schematic component

Schematic component

Schematic component

Schematic component

Schematic component

Schematic component

Schematic component

Bare PCB feature

Bare PCB feature

Bare PCB feature

Bare PCB feature

Schematic component

Schematic component

Schematic component

Schematic component

Schematic component

Schematic component

Schematic component

Schematic component
Schematic component
Schematic component

Schematic component

Schematic component
Schematic component
Schematic component
Schematic component
Schematic component
Schematic component

Schematic component

Schematic component
Schematic component

Schematic component
Schematic component
Schematic component

DNP

DNP

Schematic component

Schematic component

Schematic component
Bare PCB feature
Bare PCB feature
Bare PCB feature

Bare PCB feature
Bare PCB feature
Bare PCB feature
Bare PCB feature

Schematic component
Schematic component

Schematic component

Schematic component

Schematic component

F1 holder; no additional
PCB footprint

Reference | Final Manufacturer P/N | Description
C11, C12, C13, C14, C15, C16 B32529C0105J189 | 1u
C17 | EEH-ZS1V471P | 470u 35V HYBRID
C18 | 08055C105KAT2A | 1u 50V X7R
C19 | C0805C104K5RACTU | 100n 50V X7R
D3 | STPST10H100SB-TR | STPST10H100SB
D5 | SMBJ24CA | SMBJ24CA
F2 | 3-140-178 | SCHURTER UHS 100A 3-140-178
J1, J3 | 1932588 | MKDSP 25/2-15.00 PROVISIONAL
J4 | XT60PW-F | XT60PW-F
Q3 | BSC070N10NS5ATMA1 | BSC070N10NS5
R19 | CRCW25121K00FKEGHP | 1k
R20 | CRCW25121R00FKEGHP | 1
R21 | RC0805FR-07100RL | 100
U1 | LTC4368HMS-1#TRPBF | LTC4368HMS-1-PBF
U5 | LTC4359IMS8#TRPBF | LTC4359IMS8

## Previously Missing / Search-Only Parts — Resolved Purchasing Links

R19 MPN corrected; C17 synchronized to current schematic; C18/C19 exact 0805 parts selected; F2 stock blocker resolved with SCHURTER 3-140-178, the same-spec UHS 100 A / 50 V packaging variant available from DigiKey as cut tape.

Qty for 5 Boards | Supplier | Unit Price (USD) Extended (USD) | Status
30 Mouser | $0.30 | ORDER
5 DigiKey | $2.78 | ORDER
5 DigiKey | $0.27 | ORDER
5 DigiKey | $0.18 | ORDER
5 DigiKey | $1.44 | ORDER
5 DigiKey | $0.57 | ORDER
5 DigiKey | $1.07 | $5.37 ORDER
10 Mouser | $13.01 | ORDER
5 LCSC | $0.65 | ORDER
5 Mouser | $2.24 | ORDER
5 Mouser | $0.75 | ORDER
5 DigiKey | $0.96 | ORDER
5 DigiKey | $0.10 | ORDER
5 Mouser | $9.32 | ORDER
5 Mouser | $8.72 | ORDER

Direct Link

https://www.mouser.com/ProductDetail/TDK/B32529C0105J189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
https://www.digikey.com/en/products/detail/stmicroelectronics/STPST10H100SB-TR/18700338https://www.digikey.com/en/products/detail/littelfuseinc/SMBJ24CA/285996

https://www.digikey.com/en/products/detail/schurter-inc/3-140-178/20532481
https://www.mouser.com/en/ProductDetail/Phoenix-Contact/1932588?qs=zGjMOL9s0Z%252BnZxcpLOCAEA%3D%3D
https://lcsc.com/product-detail/plug_changzhou-amass-elec-xt60pw-f_C428722.html
https://www.mouser.com/en/ProductDetail/Infineon-Technologies/BSC070N10NS5ATMA1?qs=3Bi3m9r5MQYNTOs czKwccQ%3D%3D

https://www.mouser.com/en/ProductDetail/Vishay/CRCW25121K00FKEGHP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
https://www.mouser.com/ProductDetail/Analog-Devices/LTC4368HMS-1TRPBF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 %3D%3D

Resolution / Note

Exact 1 uF 63 V 5% film capacitor; 30 required for 5 boards. Current Mouser 10+ tier used for budget.
Schematic-selected part. 470 uF, 35 V hybrid, 11 mOhm ESR, 4 A ripple, 10 mm x 16.8 mm SMD can.
Selected procurement part: 1 uF, 50 V, X7R, 0805; active and stocked. Footprint-compatible with schematic.
Selected procurement part: 0.1 uF, 50 V, X7R, 0805; active and stocked. Footprint-compatible with schematic.

Exact schematic MPN STPST10H100SB-TR; 100 V, 10 A Schottky in DPAK. Fixes spreadsheet error where the MPN cell contained a URL. 24 V bidirectional SMBJ TVS, SMB footprint.

Preferred direct drop-in for original 3-140-177. SCHURTER datasheet lists the same 100 A / 50 V ratings, 0.71 mOhm cold resistance, 3200 A^2s melting I^2t, and same UHS package. 3-140-178 is the 1000-piece reel order number, but DigiKey offers cut tape so only 5 need to be purchased.

Exact Phoenix Contact 1932588 / MKDSP 25/2-15.00. Mouser showed stock for full 10-piece requirement.
Exact AMASS XT60PW-F right-angle female PCB connector; LCSC part C428722.

Exact Infineon BSC070N10NS5ATMA1, 100 V TDSON MOSFET; stocked.

CORRECTED MPN: spreadsheet/schematic had CRCW25121001FKEGHP. Correct Vishay CRCW-HP 2512 1 kOhm 1% pulse-rated part uses 1K00.

Exact 1 ohm, 1%, 1.5 W, pulse-withstanding 2512 resistor.

Exact 100 ohm, 1%, 0805 Yageo resistor.

Exact LTC4368HMS-1#TRPBF 10-MSOP H-grade surge/UV/OV controller; stocked.

Exact LTC4359IMS8#TRPBF 8-MSOP ideal-diode controller; stocked at Mouser.

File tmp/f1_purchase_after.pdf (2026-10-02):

Capacitor | C19 | 100n 50V X7R | KEMET | C0805C104K5RACTU

1

5

| 5 | $0.18 | $0.18 | $0.90 DigiKey | Buy

https://www.digikey.com/en/products/detail/kemet/C0805C104K5RACTU/411169

Diode / TVS | D1, D4 | SMAJ24CA | Bourns | SMAJ24CA

2

5 | 10 | $0.53 | $1.06 | $5.30 Mouser | Supplier page

https://www.mouser.com/en/ProductDetail/Bourns/SMAJ24CA?qs=A3H9pljuJ8RsSQb8zLkILA%3D%3D

Diode / TVS | D3 | STPST10H100SB | STMicroelectronics | STPST10H100SB-TR

1

5 | 5 | $1.44 | $1.44 | $7.20 DigiKey | Buy

https://www.digikey.com/en/products/detail/stmicroelectronics/STPST10H100SB-TR/18700338

Diode / TVS | D5 | SMBJ24CA | Littelfuse | SMBJ24CA

1

5 | 5 | $0.57 | $0.57 | $2.85 DigiKey | Buy

https://www.digikey.com/en/products/detail/littelfuseinc/SMBJ24CA/285996

Fuse | F1 | 7.5A MINI | Littelfuse | 029707.5WXNV

1

5

5 | $0.39 | $0.39 | $1.95 Mouser | Supplier page

https://www.mouser.com/ProductDetail/Littelfuse/029707.5WXNV?qs=vco6xy%252BeH1rKHIL2HOGn8Q%3D%3 D

Fuse | F2

SCHURTER UHS 100A 3-140-
178 | SCHURTER | 3-140-178

1

5

5 | $1.07 | $1.07 | $5.37 DigiKey | Buy

https://www.digikey.com/en/products/detail/schurterinc/3-140-178/20532481

Connector | J1, J3

MKDSP 25/2-15.00
PROVISIONAL | Phoenix Contact | 1932588

2

5 | 10 | $13.01 | $26.02 | $130.10 Mouser | Buy

https://www.mouser.com/en/ProductDetail/Phoenix-Contact/1932588?qs=zGjMOL9s0Z%252BnZxcpLOCAEA%3D%3D

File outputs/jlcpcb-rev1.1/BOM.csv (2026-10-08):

Comment | Designator | Footprint | Quantity | Manufacturer | MPN | LCSC Part #
22n | C1 | C_0805_2012Metric | 1 | TDK | C2012C0G2A223J125AC
1U0 | C2,C18 | C_0805_2012Metric | 2 | YAGEO | CC0805KKX7R9BB105 | C91185
100n | C3,C5,C8,C10 | C_0603_1608Metric | 4 | KEMET | C0603C104K4RACTU
10u | C4,C9 | C_1206_3216Metric | 2 | TDK | C3216X7R1H106K160AC
10u | C6 | C_0805_2012Metric | 1 | TDK | C2012X7R1A106K125AC
100n | C7 | C_0603_1608Metric | 1 | TDK | C1608X7R1H104K080AA
1u | C11,C12,C13,C14,C15,C16 | C_Rect_L7.2mm_W4.5mm_P5.00mm_JLC | 6 | TDK | B32529C0105J189
330u 50V HYBRID | C17 | CP_Elec_Panasonic_G16_10x16.5 | 1 | Panasonic | EEHZL1H331P
100n 50V X7R | C19 | C_0805_2012Metric | 1 | YAGEO | CC0805KRX7R9BB104 | C49678
SMAJ24CA | D1,D4 | D_SMA | 2 | Bourns | SMAJ24CA
STPST10H100SB | D3 | STPST10H100SB_DPAK | 1 | STMicroelectronics | STPST10H100SB-TR
SMBJ18CA | D5 | D_SMB | 1 | Bourns | SMBJ18CA
MINI fuse holder (blade fuse supplied separately) | F1 | Fuseholder_Blade_Mini_Keystone_3568 | 1 | Keystone | 3568
UHS 100A 50V | F2 | Fuse_SCHURTER_UHS_8.4x9.4mm | 1 | SCHURTER | 3-140-177
OSIRIS_I2C | J2 | JST_GH_BM04B-GHS-TBT_1x04-1MP_P1.25mm_Vertical | 1 | JST | BM04B-GHS-TBT(LF)(SN)
XT60PW-F | J1,J3,J4 | AMASS_XT60PW-F_1x02_P7.20mm_Horizontal_EdgeMounted | 3 | AMASS | XT60PW-F
ISC015N06NM5LF2 | Q1,Q2 | ISC015N06NM5LF2_TDSON8FL | 2 | Infineon | ISC015N06NM5LF2ATMA1
BSC070N10NS5 | Q3 | BSC070N10NS5_TDSON8 | 1 | Infineon | BSC070N10NS5ATMA1
237k | R1 | R_0805_2012Metric | 1 | YAGEO | RC0805FR-07237KL
11k8 | R2 | R_0805_2012Metric | 1 | YAGEO | RC0805FR-0711K8L
2M0 | R3 | R_0805_2012Metric | 1 | UNI-ROYAL | 0805W8F2004T5E | C26112
22k | R4 | R_0805_2012Metric | 1 | UNI-ROYAL | 0805W8F2202T5E | C17560
5m | R5 | OH_FC4L64_OHM | 1 | Ohmite | FC4L64R005FER
680k | R6 | R_0805_2012Metric | 1 | UNI-ROYAL | 0805W8F6803T5E | C17797
200k | R7 | R_0805_2012Metric | 1 | UNI-ROYAL | 0805W8F2003T5E | C17539
10 | R8,R9 | R_0805_2012Metric | 2 | UNI-ROYAL | 0805W8F100JT5E | C17415
4k7 | R10 | R_0805_2012Metric | 1 | UNI-ROYAL | 0805W8F4701T5E | C17673
1k58 | R11 | R_0805_2012Metric | 1 | YAGEO | RC0805FR-071K58L
1k0 | R12 | R_0805_2012Metric | 1 | UNI-ROYAL | 0805W8F1001T5E | C17513
54k9 | R13 | R_0805_2012Metric | 1 | YAGEO | RC0805FR-0754K9L
22M | R14 | R_0805_2012Metric | 1 | YAGEO | RC0805JR-0722ML
10k | R15,R16 | R_0805_2012Metric | 2 | UNI-ROYAL | 0805W8F1002T5E | C17414
1k | R19 | R_2512_6332Metric | 1 | Vishay | CRCW25121001FKEGHP
1 | R20 | R_2512_6332Metric | 1 | Vishay | CRCW25121R00FKEGHP
100 | R21 | R_0805_2012Metric | 1 | UNI-ROYAL | 0805W8F1000T5E | C17408
LTC4368HMS-1-PBF | U1 | MS_10-MSOP_ADI | 1 | Analog Devices | LTC4368HMS-1#TRPBF
INA228AIDGSR | U2 | VSSOP10_DGS_TEX | 1 | Texas Instruments | INA228AIDGSR
LT3010EMS8E | U3 | MSOP-8-1EP_3x3mm_P0.65mm_EP1.68x1.88mm | 1 | Analog Devices | LT3010EMS8E#TRPBF
74AUP1G07GW | U4 | SOT-353_SC-70-5 | 1 | Nexperia | 74AUP1G07GW,125
LTC4359IMS8 | U5 | MSOP-8_3x3mm_P0.65mm | 1 | Analog Devices | LTC4359IMS8#TRPBF

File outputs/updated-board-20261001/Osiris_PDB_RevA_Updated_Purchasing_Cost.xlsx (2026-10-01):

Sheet: Purchasing BOM
Osiris PDB — Updated Purchasing & Cost
Oct 1, 2026 design · USD · Budget prices carried over · 14 prices missing · Shipping/tax/assembly excluded
5 | Boards to build | Priced cost / board | $31.41 | Batch cost | $157.05 | Missing prices | 14
43 lines / 57 parts | Blank prices excluded from totals. Edit yellow Unit Cost cells. Supplier searches are labeled Search.
References | Value / Part | Manufacturer P/N | Qty / Board | Total Qty | Unit Cost (USD) | Cost / Board | Total Cost | Buy Link
C1 | 22n | C2012C0G2A223J125AC | 1 | 5 | $0.30 | $0.30 | $1.50 | Supplier page (https://www.digikey.com/en/products/detail/tdk-corporation/C2012C0G2A223J125AC/5023347)
C2 | 1U0 | C2012X7R1H105K125AB | 1 | 5 | $0.26 | $0.26 | $1.30 | Supplier page (https://www.digikey.com/en/products/detail/tdk/C2012X7R1H105K125AB/2732982)
C3, C5, C8, C10 | 100n | C0603C104K4RACTU | 4 | 20 | $0.13 | $0.52 | $2.60 | Supplier page (https://www.digikey.com/en/products/detail/kemet/C0603C104K4RACTU/411095)
C4, C9 | 10u | C3216X7R1H106K160AC | 2 | 10 | $0.98 | $1.96 | $9.80 | Supplier page (https://www.digikey.com/en/products/detail/tdk/C3216X7R1H106K160AC/9991386)
C6 | 10u | C2012X7R1A106K125AC | 1 | 5 | $0.33 | $0.33 | $1.65 | Supplier page (https://www.digikey.com/en/products/detail/tdk-corporation/C2012X7R1A106K125AC/2619198)
C7 | 100n | C1608X7R1H104K080AA | 1 | 5 | $0.10 | $0.10 | $0.50 | Supplier page (https://www.digikey.com/en/products/detail/tdk/C1608X7R1H104K080AA/513811)
C11, C12, C13, C14, C15, C16 | 1u | B32529C0105J189 | 6 | 30 |  |  |  | Supplier page (https://www.mouser.com/ProductDetail/TDK/B32529C0105J189?qs=Xovllr2ZOuY15IPkCXPF9A%3D%3D)
C17 | 470u 35V LOW-ESR | TBD | 1 | 5 |  |  |  | MPN needed
C18 | 1u 50V X7R | TBD | 1 | 5 |  |  |  | MPN needed
C19 | 100n 50V X7R | TBD | 1 | 5 |  |  |  | MPN needed
D1, D4 | SMAJ24CA | SMAJ24CA | 2 | 10 | $0.53 | $1.06 | $5.30 | Supplier page (https://www.mouser.com/en/ProductDetail/Bourns/SMAJ24CA?qs=A3H9pljuJ8RsSQb8zLkILA%3D%3D)
D3 | STPST10H100SB | STPST10H100SB-TR | 1 | 5 |  |  |  | Search supplier (https://www.mouser.com/c/?q=STPST10H100SB-TR)
D5 | SMBJ24CA | TBD | 1 | 5 |  |  |  | MPN needed
F1 | 4A MINI | 0297004.WXNV | 1 | 5 | $0.39 | $0.39 | $1.95 | Supplier page (https://www.mouser.com/ProductDetail/Littelfuse/0297004.WXNV?qs=KOeOmFnJLTo2xybF75gK9A%3D%3D)
F2 | SCHURTER UHS 100A 3-140-177 PROVISIONAL | 3-140-177 | 1 | 5 |  |  |  | Search supplier (https://www.mouser.com/c/?q=3-140-177)
J1, J3 | MKDSP 25/2-15.00 PROVISIONAL | 1932588 | 2 | 10 |  |  |  | Search supplier (https://www.mouser.com/c/?q=1932588)
J2 | OSIRIS_I2C | BM04B-GHS-TBT(LF)(SN) | 1 | 5 | $0.38 | $0.38 | $1.90 | Supplier page (https://www.mouser.com/ProductDetail/JST-Commercial/BM04B-GHS-TBTLFSN)
J4 | XT60PW-F | XT60PW-F | 1 | 5 | $1.05 | $1.05 | $5.25 | Search supplier (https://www.mouser.com/c/?q=XT60PW-F)
Q1, Q2 | ISC015N06NM5LF2 | ISC015N06NM5LF2ATMA1 | 2 | 10 | $4.07 | $8.14 | $40.70 | Supplier page (https://www.digikey.com/en/products/detail/infineon-technologies/ISC015N06NM5LF2ATMA1/22157619)
Q3 | BSC070N10NS5 | BSC070N10NS5ATMA1 | 1 | 5 |  |  |  | Search supplier (https://www.mouser.com/c/?q=BSC070N10NS5ATMA1)
R1 | 237k | RC0805FR-07237KL | 1 | 5 | $0.10 | $0.10 | $0.50 | Supplier page (https://www.digikey.com/en/products/detail/yageo/RC0805FR-07237KL/727754)
R2 | 11k8 | RC0805FR-0711K8L | 1 | 5 | $0.10 | $0.10 | $0.50 | Supplier page (https://www.digikey.com/en/products/detail/yageo/RC0805FR-0711K8L/730505)
R3 | 2M0 | RC0805FR-072ML | 1 | 5 | $0.10 | $0.10 | $0.50 | Supplier page (https://www.mouser.com/ProductDetail/YAGEO/RC0805FR-072ML)
R4 | 22k | RC0805FR-0722KL | 1 | 5 | $0.10 | $0.10 | $0.50 | Supplier page (https://www.digikey.com/en/products/detail/yageo/RC0805FR-0722KL/730683)
R5 | 5m | FC4L64R005FER | 1 | 5 | $2.69 | $2.69 | $13.45 | Supplier page (https://www.mouser.com/ProductDetail/Ohmite/FC4L64R005FER)
R6 | 680k | RC0805FR-07680KL | 1 | 5 | $0.10 | $0.10 | $0.50 | Supplier page (https://www.mouser.com/ProductDetail/YAGEO/RC0805FR-07680KL)
R7 | 200k | RC0805FR-07200KL | 1 | 5 | $0.10 | $0.10 | $0.50 | Supplier page (https://www.mouser.com/en/ProductDetail/YAGEO/RC0805FR-07200KL)
R8, R9 | 10 | RC0805FR-0710RL | 2 | 10 | $0.12 | $0.24 | $1.20 | Supplier page (https://www.digikey.com/en/products/detail/yageo/RC0805FR-0710RL/730481)
R10, R17 (DNP), R18 (DNP) | 4k7 | RC0805FR-074K7L | 1 | 5 | $0.10 | $0.10 | $0.50 | Supplier page (https://www.digikey.com/en/products/detail/yageo/RC0805FR-074K7L/727929)
R11 | 1k58 | RC0805FR-071K58L | 1 | 5 | $0.10 | $0.10 | $0.50 | Supplier page (https://www.digikey.com/en/products/detail/yageo/RC0805FR-071K58L/730449)
R12 | 1k0 | RC0805FR-071KL | 1 | 5 | $0.10 | $0.10 | $0.50 | Supplier page (https://www.digikey.com/en/products/detail/yageo/RC0805FR-071KL/727444)
R13 | 54k9 | RC0805FR-0754K9L | 1 | 5 | $0.10 | $0.10 | $0.50 | Supplier page (https://www.digikey.com/en/products/detail/yageo/RC0805FR-0754K9L/728029)
R14 | 22M | RC0805JR-0722ML | 1 | 5 | $0.16 | $0.16 | $0.80 | Supplier page (https://www.digikey.com/en/products/detail/yageo/RC0805JR-0722ML/5919060)
R15, R16 | 10k | RC0805FR-0710KL | 2 | 10 | $0.10 | $0.20 | $1.00 | Supplier page (https://www.digikey.com/en/products/detail/yageo/RC0805FR-0710KL/727535)
R19 | 1k | CRCW25121001FKEGHP | 1 | 5 |  |  |  | Search supplier (https://www.mouser.com/c/?q=CRCW25121001FKEGHP)
R20 | 1 | CRCW25121R00FKEGHP | 1 | 5 |  |  |  | Search supplier (https://www.mouser.com/c/?q=CRCW25121R00FKEGHP)
R21 | 100 | RC0805FR-07100RL | 1 | 5 |  |  |  | Search supplier (https://www.mouser.com/c/?q=RC0805FR-07100RL)
U1 | LTC4368HMS-1-PBF | LTC4368HMS-1#TRPBF | 1 | 5 |  |  |  | Supplier page (https://www.newark.com/analog-devices/ltc4368hms-1-trpbf/battery-protector-2-5v-60v-5ua/dp/17AN6956)
U2 | INA228AIDGSR | INA228AIDGSR | 1 | 5 | $4.68 | $4.68 | $23.40 | Supplier page (https://www.digikey.com/en/products/detail/texas-instruments/INA228AIDGSR/13691042)
U3 | LT3010EMS8E | LT3010EMS8E#TRPBF | 1 | 5 | $6.45 | $6.45 | $32.25 | Supplier page (https://www.digikey.com/en/products/detail/analog-devices-inc/LT3010EMS8E-TRPBF/960041)
U4 | 74AUP1G07GW | 74AUP1G07GW,125 | 1 | 5 | $0.19 | $0.19 | $0.95 | Supplier page (https://www.digikey.com/en/products/detail/nexperia-usa-inc/74AUP1G07GW-125/1300720)
U5 | LTC4359IMS8 | LTC4359IMS8#TRPBF | 1 | 5 |  |  |  | Search supplier (https://www.mouser.com/c/?q=LTC4359IMS8%23TRPBF)
F1-holder | MINI fuse holder | 3568 | 1 | 5 | $1.31 | $1.31 | $6.55 | Supplier page (https://www.digikey.com/en/products/detail/keystone-electronics/3568/2137306)
PRICED TOTAL (PARTIAL) |  |  |  |  |  | $31.41 | $157.05

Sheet: Engineering Detail
Osiris PDB Rev A — Updated Engineering BOM Detail
Source: current Osiris_PDB_RevA.kicad_sch exported 10/01/2026; 69 schematic components plus separate F1 holder. Quantity 0 means DNP or bare PCB feature.
Reference | Quantity | Value | Specification | Footprint | Manufacturer | MPN | Selection Status | Datasheet | BOM Role
C1 | 1 | 22n | 100V C0G 5% | Capacitor_SMD:C_0805_2012Metric | TDK | C2012C0G2A223J125AC | 22 nF 5% C0G in series with R4 from GATE_PIN to GND. PDB-only candidate; original Osiris eFuse configuration retained. | Open datasheet (https://product.tdk.com/en/search/capacitor/ceramic/mlcc/info?part_no=C2012C0G2A223J125AC) | Schematic component
C2 | 1 | 1U0 | 50V X7R | Capacitor_SMD:C_0805_2012Metric | TDK | C2012X7R1H105K125AB | Nominal specification verified; DC-bias and circuit validation pending | Open datasheet (https://product.tdk.com/en/search/capacitor/ceramic/mlcc/info?part_no=C2012X7R1H105K125AB) | Schematic component
C3 | 1 | 100n | 16V X7R | Capacitor_SMD:C_0603_1608Metric | KEMET | C0603C104K4RACTU | Nominal specification verified; DC-bias and circuit validation pending | Open datasheet | Schematic component
C4 | 1 | 10u | 50V X7R | Capacitor_SMD:C_1206_3216Metric | TDK | C3216X7R1H106K160AC | 10 uF local U3 input capacitor on protected PDB_VOUT. | Open datasheet (https://product.tdk.com/en/search/capacitor/ceramic/mlcc/info?part_no=C3216X7R1H106K160AC) | Schematic component
C5 | 1 | 100n | 16V X7R | Capacitor_SMD:C_0603_1608Metric | KEMET | C0603C104K4RACTU | Nominal specification verified; DC-bias and circuit validation pending | Open datasheet | Schematic component
C6 | 1 | 10u | 10V X7R | Capacitor_SMD:C_0805_2012Metric | TDK | C2012X7R1A106K125AC | A-P2 LT3010 output capacitor: require >=1 uF effective over bias/temperature and ESR <=3 ohms. Confirm manufacturer bias curve and assembled stability. | Open datasheet (https://product.tdk.com/en/search/capacitor/ceramic/mlcc/info?part_no=C2012X7R1A106K125AC) | Schematic component
C7 | 1 | 100n | 50V X7R | Capacitor_SMD:C_0603_1608Metric | TDK | C1608X7R1H104K080AA | Nominal specification verified; DC-bias and circuit validation pending | Open datasheet (https://product.tdk.com/en/search/capacitor/ceramic/mlcc/info?part_no=C1608X7R1H104K080AA) | Schematic component
C8 | 1 | 100n | 16V X7R | Capacitor_SMD:C_0603_1608Metric | KEMET | C0603C104K4RACTU | Nominal specification verified; DC-bias and circuit validation pending | Open datasheet | Schematic component
C9 | 1 | 10u | 50V X7R | Capacitor_SMD:C_1206_3216Metric | TDK | C3216X7R1H106K160AC | Output bulk capacitor; final total downstream capacitance and startup load must meet the proposed September 15 envelope. Inrush not qualified. | Open datasheet (https://product.tdk.com/en/search/capacitor/ceramic/mlcc/info?part_no=C3216X7R1H106K160AC) | Schematic component
C10 | 1 | 100n | 16V X7R; LT3010 feedback compensation | Capacitor_SMD:C_0603_1608Metric | KEMET | C0603C104K4RACTU | A-P2 U3 feedback network; layout and assembled transient verification required. | Open datasheet | Schematic component
C11 | 1 | 1u | 63V film 5% | Capacitor_THT:C_Rect_L7.2mm_W4.5mm_P5.00mm | TDK | B32529C0105J189 | Selected: 1 uF 63 V 5% polyester film. SPICE uses 0.9 uF minimum effective capacitance; verify mounted pulse and temperature behavior. | Open datasheet (https://product.tdk.com/en/search/capacitor/film/rfi_general/info?part_no=B32529C0105J189) | Schematic component
C12 | 1 | 1u | 63V film 5% | Capacitor_THT:C_Rect_L7.2mm_W4.5mm_P5.00mm | TDK | B32529C0105J189 | Selected: 1 uF 63 V 5% polyester film. SPICE uses 0.9 uF minimum effective capacitance; verify mounted pulse and temperature behavior. | Open datasheet (https://product.tdk.com/en/search/capacitor/film/rfi_general/info?part_no=B32529C0105J189) | Schematic component
C13 | 1 | 1u | 63V film 5% | Capacitor_THT:C_Rect_L7.2mm_W4.5mm_P5.00mm | TDK | B32529C0105J189 | Selected: 1 uF 63 V 5% polyester film. SPICE uses 0.9 uF minimum effective capacitance; verify mounted pulse and temperature behavior. | Open datasheet (https://product.tdk.com/en/search/capacitor/film/rfi_general/info?part_no=B32529C0105J189) | Schematic component
C14 | 1 | 1u | 63V film 5% | Capacitor_THT:C_Rect_L7.2mm_W4.5mm_P5.00mm | TDK | B32529C0105J189 | Selected: 1 uF 63 V 5% polyester film. SPICE uses 0.9 uF minimum effective capacitance; verify mounted pulse and temperature behavior. | Open datasheet (https://product.tdk.com/en/search/capacitor/film/rfi_general/info?part_no=B32529C0105J189) | Schematic component
C15 | 1 | 1u | 63V film 5% | Capacitor_THT:C_Rect_L7.2mm_W4.5mm_P5.00mm | TDK | B32529C0105J189 | Selected: 1 uF 63 V 5% polyester film. SPICE uses 0.9 uF minimum effective capacitance; verify mounted pulse and temperature behavior. | Open datasheet (https://product.tdk.com/en/search/capacitor/film/rfi_general/info?part_no=B32529C0105J189) | Schematic component
C16 | 1 | 1u | 63V film 5% | Capacitor_THT:C_Rect_L7.2mm_W4.5mm_P5.00mm | TDK | B32529C0105J189 | Selected: 1 uF 63 V 5% polyester film. SPICE uses 0.9 uF minimum effective capacitance; verify mounted pulse and temperature behavior. | Open datasheet (https://product.tdk.com/en/search/capacitor/film/rfi_general/info?part_no=B32529C0105J189) | Schematic component
C17 | 1 | 470u 35V LOW-ESR | Local low-ESR bulk capacitor at ESC connector; final capacitance and ripple-current rating must be coordinated with the ESC vendor. | Capacitor_SMD:CP_Elec_10x10.5 |  |  | PROVISIONAL 4S value; use 35 V minimum rating and qualify ripple current, ESR, temperature, polarity, and inrush. |  | Schematic component
C18 | 1 | 1u 50V X7R | 50 V X7R ceramic bypass for the ESC branch | Capacitor_SMD:C_0805_2012Metric |  |  |  |  | Schematic component
C19 | 1 | 100n 50V X7R | 50 V X7R high-frequency bypass for the ESC branch | Capacitor_SMD:C_0805_2012Metric |  |  |  |  | Schematic component
D1 | 1 | SMAJ24CA | Bidirectional 400 W TVS; 24 V standoff, 26.7 V min breakdown, 38.9 V clamp | Diode_SMD:D_SMA | Bourns | SMAJ24CA | Bidirectional 24 V TVS candidate; 38.9 V specified clamp is pulse-condition dependent. Source energy, ringing and downstream peak voltage remain open. | Open datasheet | Schematic component
D3 | 1 | STPST10H100SB | 100V 10A | PDB_Footprints:STPST10H100SB_DPAK | STMicroelectronics | STPST10H100SB-TR | Selected power clamp. Connect both anode leads to GND and cathode tab to PDB_VOUT. Pulse/thermal validation required. | Open datasheet (https://www.st.com/resource/en/datasheet/stpst10h100sb.pdf) | Schematic component
D4 | 1 | SMAJ24CA | Bidirectional 400 W TVS; 24 V standoff, 26.7 V min breakdown, 38.9 V clamp | Diode_SMD:D_SMA | Bourns | SMAJ24CA | Selected: local bidirectional clamp from IDEAL_IN to U5 reference IDEAL_VSS. | Open datasheet | Schematic component
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

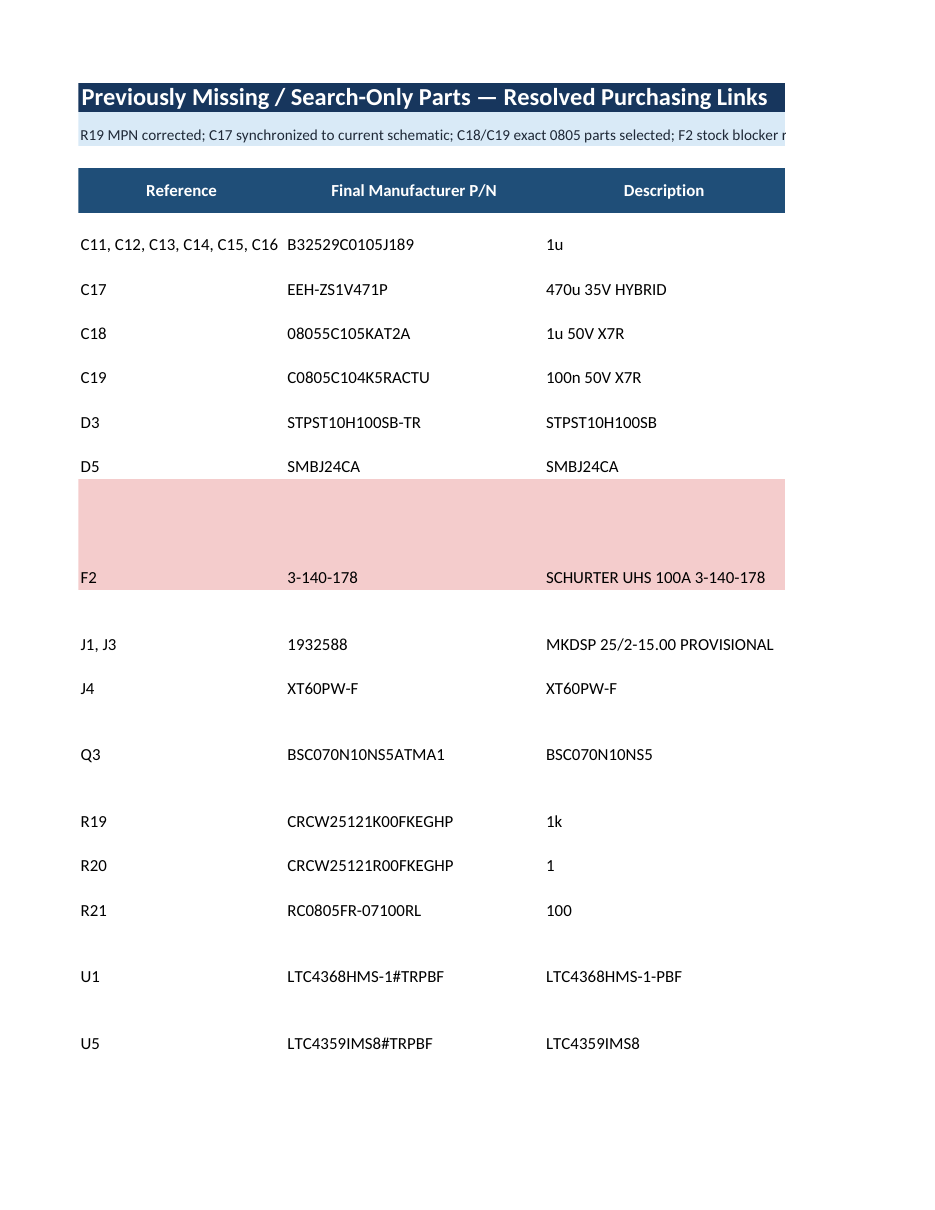
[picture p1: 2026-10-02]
tmp/f1_bom_before-34.png

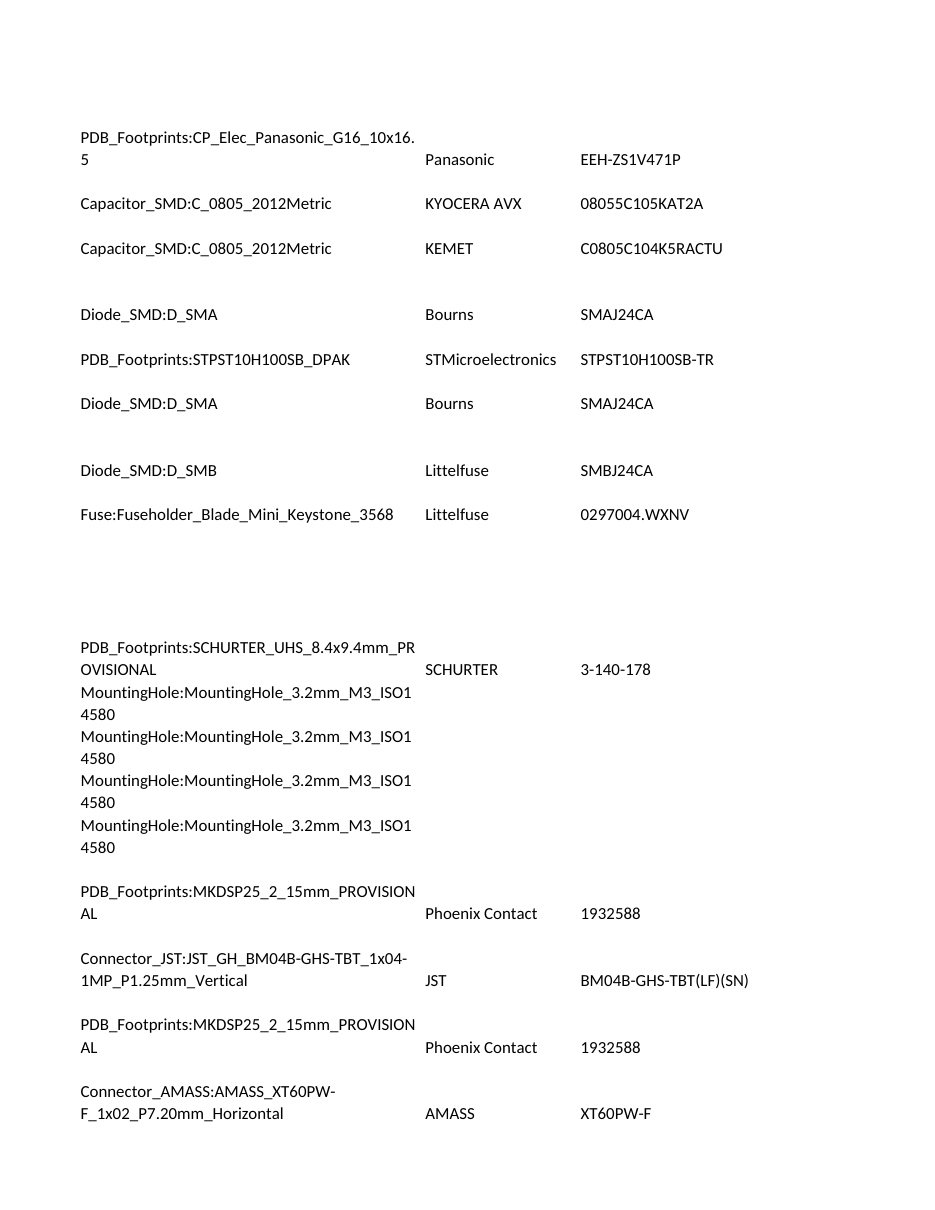
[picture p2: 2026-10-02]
tmp/f1_bom_before-19.png

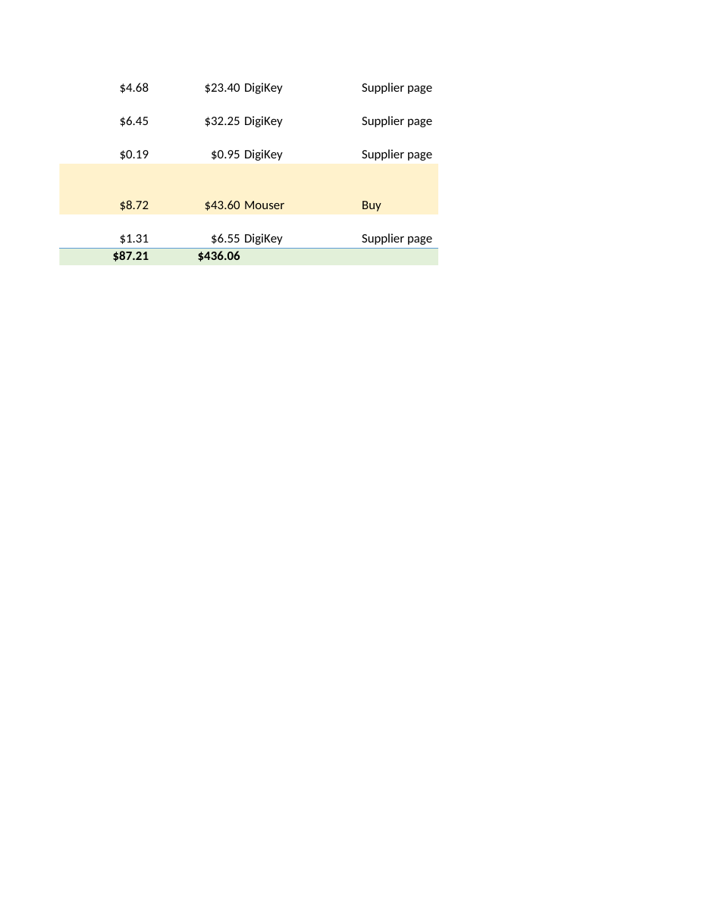
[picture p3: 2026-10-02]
tmp/f1_bom_before-09.png

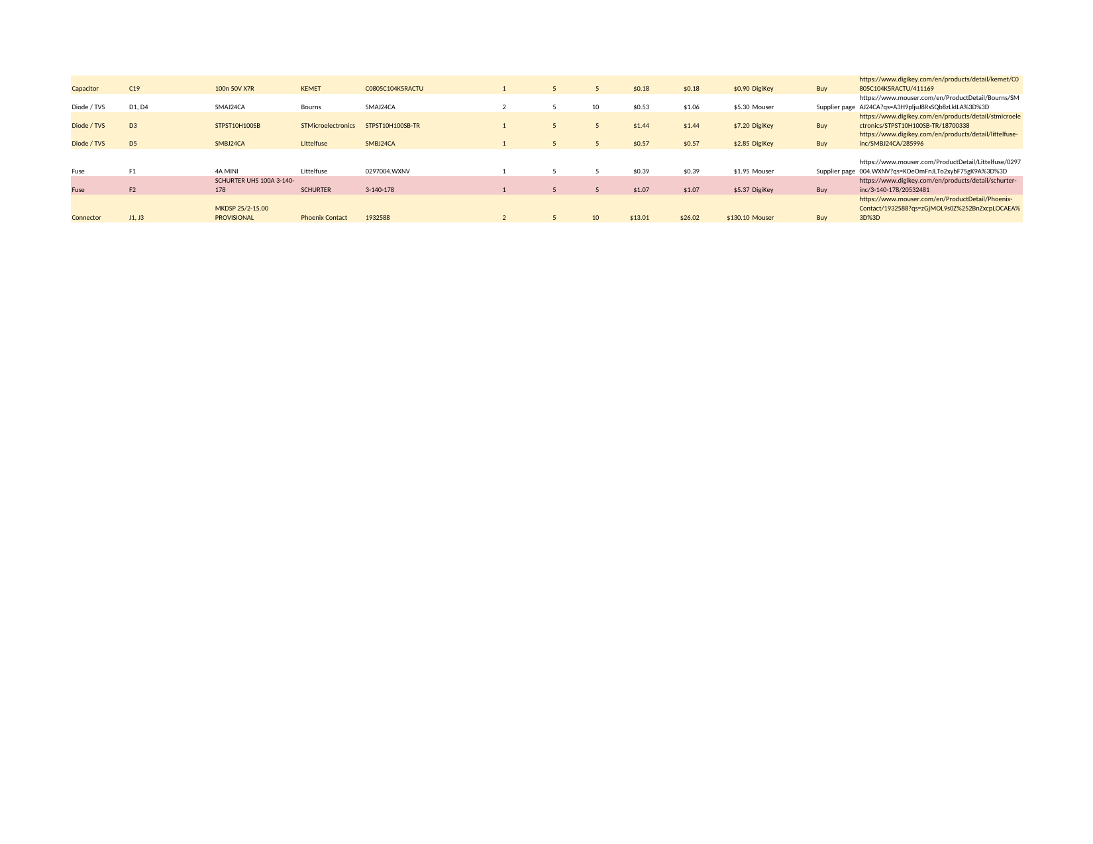
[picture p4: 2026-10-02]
tmp/f1_purchase_before-1.png

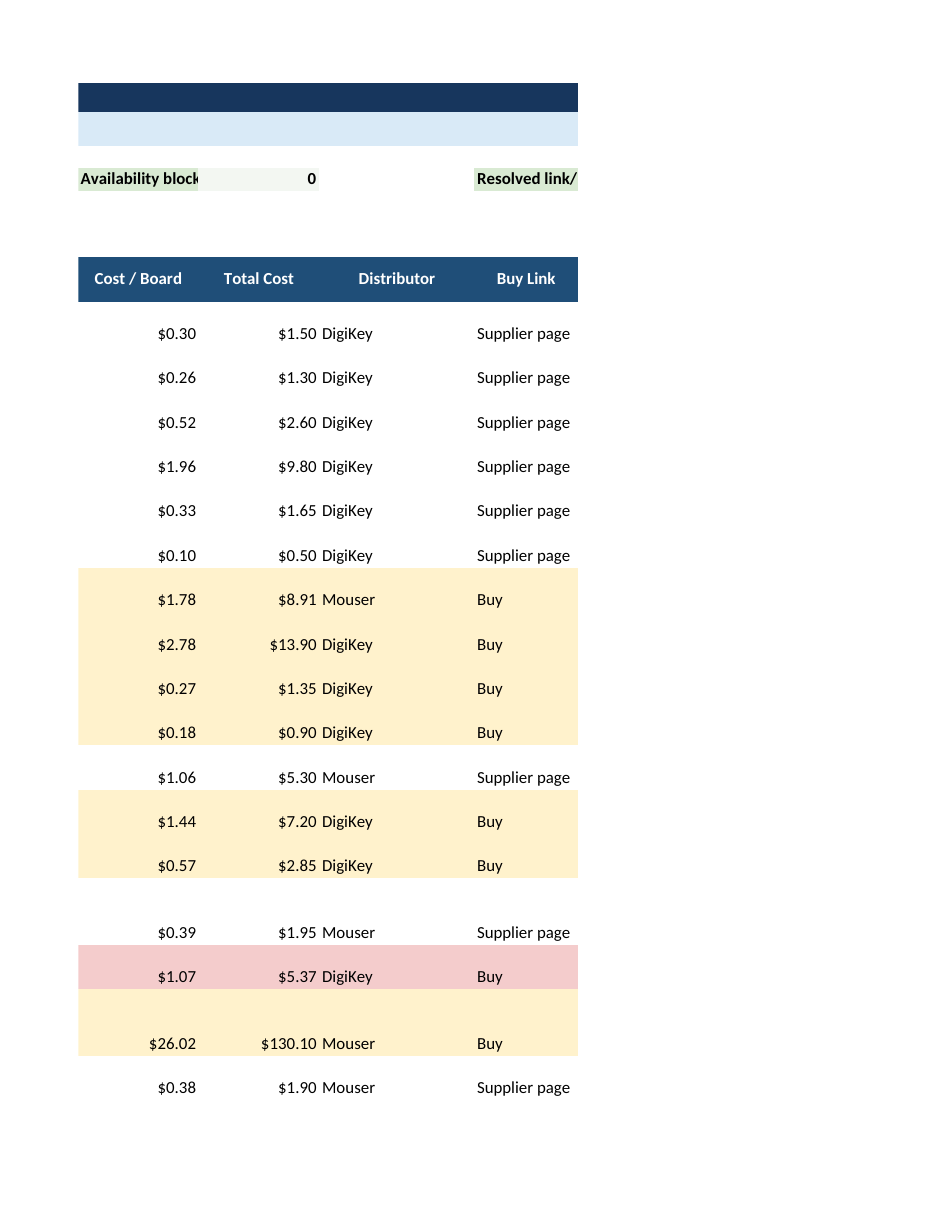
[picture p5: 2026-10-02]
tmp/f1_bom_before-07.png

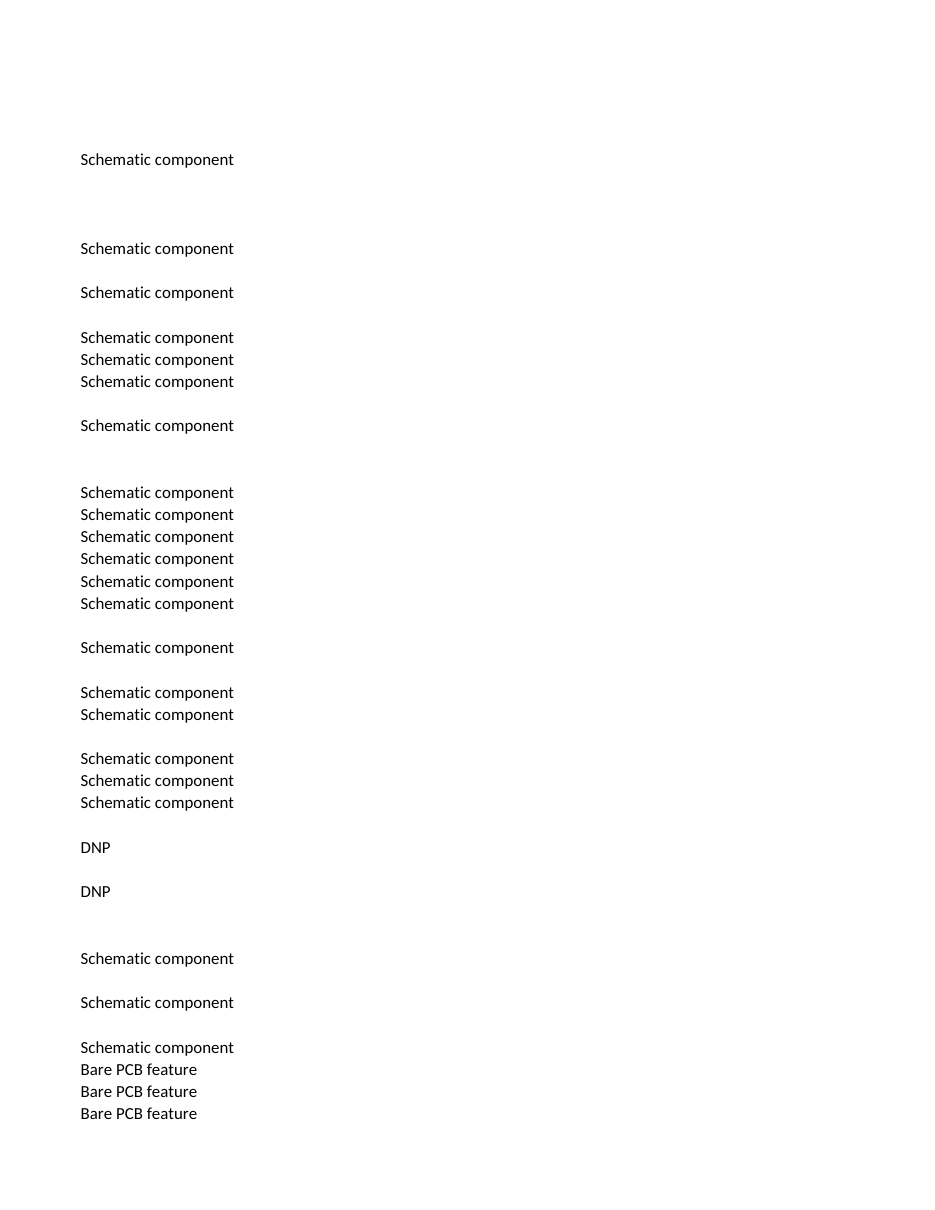
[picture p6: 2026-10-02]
tmp/f1_bom_before-32.png

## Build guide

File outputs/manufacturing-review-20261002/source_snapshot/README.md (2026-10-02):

# Osiris PDB Rev A

This repository contains the current KiCad 10 power distribution board project.
Open [Osiris_PDB_RevA.kicad_pro](Osiris_PDB_RevA.kicad_pro) to edit the schematic and PCB. The `Libraries` and `Datasheets` directories contain project resources; keep them alongside the project files.

The PCB is the compact layout restored on October 1, 2026: J1 is on the left, J3 is on the right, and the ESC capacitor sits above the central circuitry. The schematic uses the matching connector and net assignments. Local library names and resource paths are configured for this project directory.

This revision is a prototype. Manufacturing preparation on October 2, 2026 resolved the redundant output-copper zone, improved J4 mounting-slot annular rings, filled missing part selections, and tightened silkscreen checks. Final checks report no schematic electrical-rule violations, no PCB design-rule violations, no unconnected PCB items, and no schematic parity issues.

The JLCPCB prototype quotation package and [release review](outputs/manufacturing-review-20261002/RELEASE_REVIEW.md) are in `outputs/manufacturing-review-20261002`. Exact JLCPCB parts matching, assembly-preview approval, and stackup/panel confirmation remain necessary before ordering. The 60 A continuous / 100 A for 30 seconds ESC targets still require physical qualification. Use the new manufacturing BOM for this design; the older cost workbook does not include every current selection.

The updated purchasing and cost workbook, with engineering, purchasing, and missing-link previews, is in `outputs/updated-board-20261001`. Component datasheets and local KiCad libraries are kept with the project. Temporary generation scripts, bundled software dependencies, and intermediate inspection files are excluded.

To repeat the checks from this directory:

```sh
kicad-cli sch erc Osiris_PDB_RevA.kicad_sch
kicad-cli pcb drc --schematic-parity Osiris_PDB_RevA.kicad_pcb
```

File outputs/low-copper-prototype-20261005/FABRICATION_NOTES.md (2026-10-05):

# Osiris PDB REV1.1 Low Copper prototype fabrication

- Four-layer FR-4: F.Cu / In1.Cu / In2.Cu / B.Cu, 1.6 mm finished thickness.
- **1 oz outer / 0.5 oz inner copper**: nominal 35 / 17.5 / 17.5 / 35 µm. Confirm availability for the chosen assembly service. These are requested nominal copper weights, not measured factory minima.
- Use a standard compatible manufacturer stackup. Source dielectric entries are nominal thickness bookkeeping, not a prescribed dielectric/core build or impedance specification.
- ENIG finish, green solder mask proposed. Finished outline 127.5 × 65 mm from Edge.Cuts centerline. Stroke bounds add 0.05 mm; do not enlarge the board by this stroke.
- Separate metric PTH and NPTH drills, 263 plated holes/slots and four 3.2 mm NPTH mounting holes. Two 0.6 × 1.7 mm plated mounting slots at J4. Preserve single-board layer registration.
- Confirm finished hole/barrel plating and inspect solder fill on J1/J3. DC screening assumed 25 µm via barrel copper; the actual plating must be confirmed, and that model assumption is not a factory guarantee.
- Do not alter copper geometry, remove distributed vias, or change copper weights without updating the review.
- Electrical net test; comparison netlist supplied in checks/LowCopper.ipc.
- Factory panelization/rails/tooling outside finished-board current paths; confirm mixed SMT/THT assembly and support for the tall terminals.
- Review paste/reflow for F2 and power-device pads; inspect hidden joints. Insert the separately supplied F1 blade fuse after soldering.
- **Test prototype. Current capacity, enclosure temperatures, voltage drop and fault duty have not been physically qualified.**

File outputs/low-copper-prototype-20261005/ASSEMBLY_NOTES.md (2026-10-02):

# Assembly instructions

The fitted build has 56 component placements, all on the top side. JLCPCB BOM/CPL are quotation inputs pending exact part matching and factory preview.

## Fitting instructions

- F1 placement is the **Keystone 3568 fuse holder**, not the removable blade fuse. Supply one Littelfuse 029707.5WXNV per board separately; insert after soldering, cleaning, and inspection.
- F2: fit SCHURTER **3-140-177**, 100 A / 50 VDC UHS. Do not substitute another family or use the old blade-fuse footprint.
- R17/R18: **do not populate**. The host owns the I2C pull-ups.
- H1–H4 are empty mounting holes. TP1–TP7 are bare copper test pads; no separate parts.
- Q1/Q2: exact Infineon ISC015N06NM5LF2ATMA1. Pins 1–3 source, 4 gate, 5–8 drain; custom pad primitives provide the enlarged source and drain lands. Review stencil deposition and hidden-joint soldering.
- U1: exact **LTC4368HMS-1#TRPBF**. The -2 variant is not an approved substitute.
- D3: both anode leads connect to GND; cathode tab connects to PDB_VOUT. Confirm the package orientation in the matched preview.
- D1/D4/D5 are bidirectional TVS parts. Fit the exact selected manufacturers/MPNs; no generic manufacturer substitutions are approved by this BOM.
- Verify C17/C9 capacitor polarity against copper/net assignments. All IC pin-1 positions must agree with the pad-1 table and assembly drawing.
- Confirm J1/J3's tall screw-terminal insertion and soldering process, mechanical support, and solder fill. Fit the JST and XT60 connectors in the specified orientation.

## Connector continuity table

| Connector | Pin | Connection |
| --- | --- | --- |
| J1 pack input | 1 | GND |
| J1 pack input | 2 | VBAT_RAW positive |
| J3 ESC output | 1 | GND |
| J3 ESC output | 2 | ESC_VBAT positive, after F2 |
| J4 avionics output | 1 | GND |
| J4 avionics output | 2 | PDB_VOUT protected positive |
| J2 host interface | 1 | INA_ALERT; no power feed |
| J2 host interface | 2 | I2C SCL |
| J2 host interface | 3 | I2C SDA |
| J2 host interface | 4 | GND |

Pin numbers are PCB/schematic pad numbers. Verify mating-harness contact numbers and physical polarity; visual connector gender alone is insufficient.

## Placement convention

Coordinates are millimeters, X right / Y up, using the KiCad absolute datum. THT footprints with offset pad-1 origins have been centered on their body/courtyard for insertion; these positions still need factory confirmation. SMT origins are retained. `Placement_Review.csv` records origins, proposed centers and actual pad-1 coordinates. Factory library rotations have not been assumed. Check all matched bodies and polarities in the assembly preview before order release.

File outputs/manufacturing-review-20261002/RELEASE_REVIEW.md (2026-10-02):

# Osiris PDB Rev A — JLCPCB prototype manufacturing review

Prepared October 2, 2026. Source schematic revision: A-P6-PROTOTYPE.

**Status: package prepared for quotation and manufacturer DFM review. Order release remains pending parts matching, assembly-preview approval, and confirmation of stackup and panelization. The 60 A continuous / 100 A for 30 seconds ESC targets remain unqualified. No order has been submitted.**

## Completed

- Removed the redundant F.Cu PDB_VOUT zone contained within the existing F.Cu/B.Cu zone, then refilled and saved the board.
- Final ERC and PCB DRC report zero violations, zero unconnected items, and zero schematic parity issues. Warnings and exclusions were included. The only ignored PCB check concerns track-tuning profiles.
- Enabled 0.15 mm silkscreen clearance, 1.0 mm minimum text height, and 0.15 mm text stroke. Enlarged undersized reference text, thickened test-point labels, adjusted film-capacitor outlines, and removed duplicate IC markers. U2's crowded silk marker was removed; its fabrication-layer marker and the assembly drawing identify pin 1.
- Increased the two J4 plated mounting-slot pads from 0.9 × 2.0 mm to 1.2 × 2.3 mm. Their 0.6 × 1.7 mm drills are unchanged. End and side annular rings are now 0.30 mm. Saved this footprint in the local project library and updated the schematic library link.
- Added exact ordering codes for C18 (TDK C2012X7R1H105K125AB), C19 (KEMET C0805C104K5RACTU), and D5 (Bourns SMBJ24CA). These preserve the existing nominal values and footprints. Selection does not establish current JLCPCB inventory or transient qualification.
- Added the Keystone 3568 holder as the fitted F1 item in the JLCPCB BOM. The Littelfuse 029707.5WXNV blade fuse is listed separately for insertion after soldering.
- Generated 11 Gerber layers, separate plated/non-plated drill files, a Gerber job file, IPC-D-356 netlist, BOM, CPL, placement review, DNP list, assembly drawing, and fabrication notes.
- Validated agreement between the BOM and CPL for **56 fitted parts in 41 BOM groups**. R17/R18 are DNP; H1–H4 are bare mounting holes; TP1–TP7 are bare test pads. No bottom-side components are fitted in this build.
- Compared the edited PCB with the original Git revision: track/via geometry, footprint positions/orientations, pad nets, and drill sizes are unchanged. The only pad-size changes are the two documented J4 mounting-slot annular rings.
- Parsed all 13 Gerber/drill files with an independent reader and visually inspected copper, solder paste, and silkscreen exports. The reader accepts KiCad's drill files with a G90-header-order warning. KiCad's drill report gives 241 plated holes/slots and four non-plated mounting holes.

## Package use

Upload `Osiris_PDB_RevA_JLCPCB_Gerbers.zip` for PCB quotation. Use `assembly/JLCPCB_BOM.csv` and `assembly/JLCPCB_CPL.csv` for assembly quotation. The full review ZIP contains notes, checks, the supply-separately list, and assembly drawings; it is not a substitute for the Gerber-only upload ZIP.

`source_snapshot` freezes the CAD files and local libraries used for this export. `SHA256_MANIFEST.json` records source and delivered-file hashes. Standard KiCad libraries and the original repository's Datasheets directory are external resources; they are not bundled in the source snapshot. The annotated drawing is supplied as SVG and PNG.

The BOM's LCSC-number fields are intentionally blank. Match by **both exact manufacturer and exact MPN** in JLCPCB's order interface. A matching family name is insufficient. In particular, do not replace LTC4368 **-1** with **-2**, or substitute a different MOSFET or generic SMBJ24CA manufacturer without an engineering review. Public catalog searches did not establish exact assembly availability for the selected U1, Q1/Q2, or F2. J1/J3 have an LCSC listing, but that does not establish JLCPCB assembly stock or acceptance.

Use Standard PCBA as the planning route because of the heavy-copper stackup, large terminal blocks, and mixed SMT/THT assembly. Confirm the selected assembly service at quotation. The board outline is 127.5 × 65.0 mm; request a routed manufacturing panel with rails and fiducials meeting JLCPCB's minimum assembly dimensions. Two 5 mm rails above and below would give a nominal 127.5 × 75 mm bounding size, subject to their final fixture/panel design. Supply single-board data and let JLCPCB repeat it. Keep tabs, tooling holes, and fiducials off the finished board's current paths.

Coordinates use KiCad's absolute datum in millimeters, X to the right and Y upward; KiCad board Y values are negated in the CPL. THT entries use the body/courtyard centers instead of pad-1 origins. SMT entries retain component origins; asymmetric courtyards were not used as SMT body centers. `Placement_Review.csv` records the original coordinates and actual pad-1 locations. **Every polarity, pin-1 position, rotation, and body alignment must be checked against JLCPCB's matched library preview before order release.** No assumed library rotation corrections have been applied.

## Power-path desk review

| Path | Findings | Qualification still needed |
| --- | --- | --- |
| J1 → F2 → J3 ESC | F2 connects raw input directly to ESC_VBAT. ESC positive uses a broad top zone plus In2 copper. Eleven 0.6 mm-drill stitching vias join ESC copper. J1/J3 each provide four plated pins per pole. Ground return includes F.Cu, In1, and B.Cu. The avionics protection chain is bypassed. | Current-sharing, copper constrictions, connector solder fill, terminal/harness heating, and voltage drop. Check via plating and current sharing rather than treating the via count as an ampacity rating. |
| F2 overload backup | SCHURTER 3-140-177 is 100 A / 50 VDC. The saved 3.4 × 6.15 mm pads, 3.3 mm gap, and ±3.35 mm centers agree with the manufacturer's drawing. | Manufacturer performance was measured on **22 mm-wide, 210 µm copper**, which differs from this 70 µm/layer design. Typical cold resistance 0.71 mΩ implies 2.56 W at 60 A and 7.1 W at 100 A; operating resistance rises with temperature. The published typical 110 mV drop at 100 A corresponds to 11 W. Derating and solder-joint heating need bench measurements. |
| Pack fault interruption | F2's interrupt rating depends on voltage: 600 A at 50 V, 1000 A at 32 V, 1300 A at 24 V, 2000 A at 16 V. F1 is rated 1000 A at 32 V. | Establish maximum pack voltage and prospective short-circuit current, including harness resistance. Do not assume the 2000 A / 16 V figure applies to a fully charged 16.8 V pack. Confirm a suitable voltage-specific rating and clearing-energy coordination. |
| J1 → F1 → Q3/U5 → Q1/Q2/U1 → R5 → J4 avionics | Separate protected branch; planning load 5 A. F1 is 7.5 A, R5 is 5 mΩ / 2 W, and the stated electronic breaker is nominally 10 A. Shunt dissipation is 0.125 W at 5 A and 0.5 W at 10 A. Q1/Q2 have custom source/drain copper primitives; their small anchor dimensions do not represent the complete pads. | Fuse/electronic-breaker coordination, startup/inrush and FET safe operating area, Kelvin accuracy, reverse-input/current blocking, effective C6 capacitance, and U3 stability. This review did not establish an assembled fault-clearing response. |
| ESC transient network | C17 is 470 µF / 35 V; D5 is a 24 V-standoff TVS. A 24 V-standoff TVS does not impose a 24 V maximum, and its stated 38.9 V clamp can exceed C17's 35 V rating. | Capture installed harness hot-plug/load-step/ringing waveforms and pulse energy. Demonstrate acceptable capacitor voltage and ripple, or revise the clamp/capacitor design before unrestricted pack use. |

The ESC branch has **no active reverse-polarity protection**. Review and label the keyed/verified pack harness accordingly. Do not apply the avionics branch's protection claims to J3.

Footprint checks covered the fuse pad drawing, the F1 holder's 9.92 × 3.40 mm hole pattern and 1.78 mm holes, J1/J3's 15 mm pole pitch and 1.6 mm drills, J4's slots, and Q1/Q2's source/gate/drain mapping. Physical samples, enclosure fit, mating cable polarity, and full solder-process qualification remain open. J1/J3 are approximately 39 mm above the PCB and need factory handling/fixture confirmation. No enclosure or harness model was supplied for collision testing.

## Before paying for prototypes

1. Confirm exact parts matching and available quantities for all 41 BOM groups. Resolve special sourcing/consignment for unavailable parts and get confirmation that JLCPCB will solder the tall J1/J3 terminals and F1 holder. Include the removable blade fuse as a separate supply item.
2. Confirm **four layers, 1.6 mm, ENIG, 2 oz finished copper on every copper layer**. JLCPCB's published option ties 2 oz inner copper to the JLC3313 stackup. The saved generic dielectric thicknesses are not a supplier-approved JLC3313 stackup. Obtain the actual build-up and plating specification; do not accept thinner inner copper as a silent substitution.
3. Confirm routed rails/fiducials, through-hole soldering, large-fuse paste deposition and reflow profile, and inspection of hidden power-device joints.
4. Check the matched assembly preview against the supplied drawing and pad-1 table. Resolve body-position and library-rotation corrections in a revised CPL, then regenerate its validation/checksums.
5. Approve the prototype quantity, quote, and the controlled bring-up plan below. This package does not authorize a production-volume build or establish the provisional current rating.

## Prototype bring-up and qualification plan

Record board serial, actual stackup, assembly lot, fixture/harness, supply settings, ambient temperature, measured voltages/current, temperatures, and scope captures for each test. Keep original measurements; do not mark a test passed without results.

1. **Incoming inspection:** confirm board dimensions, connector seating/polarity, all four layers' copper specification, plated-hole solder fill, fuse joints, IC orientation, and DNP R17/R18. Check continuity against the connector table in `assembly/ASSEMBLY_NOTES.md` and inspect for supply-to-ground shorts. Validate enclosure/cable fit before power.
2. **First power:** disconnect the ESC and host. Use a current-limited bench supply with no external load. Ramp within the intended operating range, checking unexpected current, heating, and the approximately 3.29 V local rail. A provisional 3.2–3.4 V rail window is a bring-up screen; final limits must use the regulator/divider tolerances and temperature requirements.
3. **Avionics branch:** apply incremental loads through J4 up to the intended 5 A. Measure shunt voltage with Kelvin probes (nominally 25 mV at 5 A), INA228 response, rail stability, and temperatures. Test startup with the actual downstream capacitance. Check UV/OV thresholds, fault/alert behavior and current limiting against the selected -1 controller datasheet and component tolerance envelope. Use a controlled electronic load for fault tests. Verify reverse blocking on this branch with J3 disconnected.
4. **Host interface:** verify cable contacts; J2 pin 1 is INA_ALERT, pin 2 SCL, pin 3 SDA, pin 4 GND. Confirm host-owned pull-ups and host-off behavior. Start with the saved 100 kHz / ≤90 pF bus assumption. Compare measured current and bus voltage with calibrated instruments.
5. **ESC low-load/transient testing:** start at low current using the intended harness. Capture hot-plug and load-step peaks at J1, J3, and C17 with appropriate probing. Keep C17 voltage within its rating and verify TVS pulse duty. Resolve excessive peaks before high-current tests.
6. **High-current qualification:** after the preceding tests pass, increase current in controlled steps while logging terminal, fuse, copper, via-region and ground-return temperatures and voltage drop. Establish an agreed maximum ambient/enclosure condition and thermal acceptance limits from component ratings before testing 60 A to steady state. The common input must carry ESC plus avionics load (65 A at simultaneous 60 A ESC + 5 A avionics). Attempt the provisional 100 A / 30 s ESC burst only after lower-load thermal results support it; input then carries up to 105 A with avionics. Repeat after cooldown and inspect solder joints afterward. Stop if temperature rises without stabilizing or approaches the agreed limit.
7. **Fault qualification:** establish source short-circuit duty and verify fuse/PCB/harness clearing coordination using an appropriately rated controlled fixture. Do not use an uncontrolled pack short as a bring-up test. Reinspect and remeasure the board following fault tests.

## Sources

- [JLCPCB PCB capabilities](https://jlcpcb.com/capabilities/pcb-capabilities/)
- [JLCPCB assembly capabilities](https://jlcpcb.com/capabilities/pcb-assembly-capabilities)
- [JLCPCB copper weights](https://jlcpcb.com/help/article/jlcpcb-copper-weight) and [2 oz inner-layer option](https://jlcpcb.com/quote/pcbOrderFaq/Copper%20Weight)
- [JLCPCB BOM](https://jlcpcb.com/help/article/bill-of-materials-for-pcb-assembly), [CPL](https://jlcpcb.com/help/article/pick-place-file-for-pcb-assembly), and [parts matching/sourcing](https://jlcpcb.com/help/article/common-bom-and-cpl-matching-issues-and-explanations)
- Local SCHURTER_UHS.pdf pp. 2–3, Keystone_3568.pdf drawing, Littelfuse_297_MINI.pdf pp. 1–2, Datasheet ISC015N06NM5LF2.pdf pp. 1 and 11, and AMASS_XT60PW-F.pdf drawing in the project's Datasheets directory.
- [Phoenix Contact 1932588](https://www.phoenixcontact.com/en-sg/products/printed-circuit-board-terminal-mkdsp-25-2-1500-1932588)
- [C18 manufacturer specifications](https://product.tdk.com/en/search/capacitor/ceramic/mlcc/info?part_no=C2012X7R1H105K125AB), [C19 manufacturer specifications](https://search.kemet.com/download/specsheet/C0805C104K5RACTU), and [D5 manufacturer datasheet](https://www.bourns.com/docs/product-datasheets/smbj.pdf)

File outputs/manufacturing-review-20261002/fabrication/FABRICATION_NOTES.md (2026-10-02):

# Osiris PDB Rev A prototype fabrication requirements

For JLCPCB quotation/DFM review; obtain agreement before manufacturing.

- FR-4, four copper layers: F.Cu / In1.Cu / In2.Cu / B.Cu.
- Finished thickness 1.6 mm. ENIG finish; green solder mask proposed for prototypes.
- **2 oz finished copper (nominal 70 µm) on all four layers. Inner copper must not default to 0.5 oz.** Confirm JLC3313 availability and supply the actual approved dielectric build-up. Generic source dielectric values are not an approved factory stackup.
- Board outline 127.5 × 65.0 mm from Edge.Cuts centerline. Gerber aperture bounds include the 0.05 mm outline stroke; do not enlarge the board by this stroke.
- Routed outline; no V-scoring through the finished board. Four 3.2 mm NPTH mounting holes.
- Separate metric PTH and NPTH Excellon files; do not mirror or recenter individual layers. Two 0.6 × 1.7 mm plated mounting slots at J4.
- Electrical net test using supplied fabrication data; IPC-D-356 comparison netlist is in the checks folder of the full package.
- Confirm hole/barrel plating, especially the current-sharing connector holes and 0.6 mm stitching vias. Preserve all copper/via geometry; no silent copper-weight or via substitutions.
- Request Standard mixed SMT/THT assembly. Supply single-board data and factory panelization. Provide rails, tooling holes and fiducials meeting assembly minimum dimensions; proposed 5 mm rails above/below the board require manufacturer fixture/tab review.
- Keep all added panel features outside finished-board copper paths and mounting/connector clearances. Confirm depaneling method and mechanical support for the tall J1/J3 terminals.
- Factory to confirm paste/stencil and reflow process for F2 and the power-device copper pads. Inspect hidden joints and plated-hole solder fill. Supply F1 blade fuse separately and insert after soldering.
- Prototype only. Continuous/burst ampacity and fault interruption of the assembled board are not qualified.

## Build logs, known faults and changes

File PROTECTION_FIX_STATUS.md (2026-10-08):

# Osiris PDB REV1.1 protection corrections

October 8, 2026. Revision stays 1.1; outline and copper build stay 82.5 x 65 mm, four layers, 1 oz outer / 0.5 oz inner. These are engineering corrections, not a full electrical qualification or flight release.

| Item | Implemented correction | Remaining evidence |
|---|---|---|
| TVS / capacitor voltage coordination | D5 SMBJ24CA -> SMBJ18CA. C17 470 uF / 35 V EEHZS1V471P -> 330 uF / 50 V EEHZL1H331P. Same SMB/G16 footprints and pads. | Installed ESC/harness overshoot, regeneration, TVS pulse energy, temperature and capacitor ripple/bulk requirement. |
| Startup / MOSFET SOA | Corrected component identification and added startup, inrush and single-FET stress equations to workbook. Existing Q1/Q2 are linear-mode-rated ISC015N06NM5LF2, not the ordinary ISC015N06NM5. | Actual host startup waveform, connected peripheral capacitance, hot-case SOA trajectory and repeated-retry thermal test. No SOA pass claimed. |
| Retry calculation | C3 is 100 nF on U1 RETRY: nominal delay 550 ms. C1 is 22 nF in series with R4=22 kOhm in the gate-ramp branch. | C3 tolerance/DC bias and IC timing variation; fault/recovery scope test. |
| Host bus / cable | Found 5 V-to-ALERT cable conflict; specified three-conductor J2-to-J28 harness. Changed host R74/R75 to 4.7 kOhm. PDB pull-ups remain DNP. | Physical cable checks, rise-time and independent power-state test. |
| Firmware | Added tested, portable INA228 driver: correct address/range/calibration/sign/diagnostics/configuration-loss handling. | Integrate into the actual STM32 firmware project; compile for target, flash and compare against calibrated instruments. No application firmware was found locally. |
| Pack fault interruption | Verified F2's actual voltage-specific interruption figures and recovered 4S/AERO SELFIE 45 A 4-in-one context from earlier discussion. Added a concrete external-fuse proposal below. | Pack/harness minimum resistance and inductance, guaranteed total clearing data, physical protective-device installation and current envelope. Not closed. |

## Transient component correction

At 16.8 V full-charge input, SMBJ18CA has 18 V standoff. Bourns specifies 29.2 V maximum clamp at 20.6 A (10/1000 us) and 38.0 V at 103 A (8/20 us), at 25 C. These are 20.8 V and 12.0 V below the new 50 V capacitor rating at those stated pulse conditions. They are not maximum system voltages for arbitrary pulse currents or temperature. C17's nominal energy at 16.8 V is 0.04657 J. The new ZL G16 part is 330 uF +/-20%, 12 mOhm ESR at 100 kHz/20 C, 5 Arms at 100 kHz/125 C. The reduced capacitance must not replace the ESC manufacturer's required capacitor at the ESC terminals. Supply is explicitly 4S; this TVS selection is not for 6S use.

Sources: [Bourns SMBJ](https://www.bourns.com/docs/product-datasheets/smbj.pdf), [Panasonic ZL](https://industrial.panasonic.com/cdbs/www-data/pdf/RDD0000/ast-ind-303928.pdf). D5's old sourcing record and C17's old price/stock no longer apply; the procurement workbook marks both replacements unquoted. Its total is a quoted-items subtotal until these are priced.

## Startup calculation and disposition

The actual gate network follows the LTC4368 application circuit: GATE directly drives Q1/Q2, with R4=22 kOhm and C1=22 nF to ground. C2=1 uF is on the output/sense node; it is not the gate-ramp capacitor. C3=100 nF is the retry capacitor.

Use dV/dt = Igate/Cgate, Icapacitive = Cload Igate/Cgate, and tcharge = Cgate Vin/Igate as first-order screening equations. The controller's 12 V test condition gives 20/35/60 uA gate pull-up magnitudes. C1 is +/-5%. At 16.8 V, nominal ramp is 10.56 ms; the slow screening corner is 19.404 ms. These ignore intrinsic gate charge and load behavior, and are not guaranteed timing across the full operating range.

The current Osiris netlist has 1 uF on VBATT_OUT and 49.2 uF nominal on VIN (six 4.7 uF plus 1 uF plus two 10 uF). The main-board LM73100 intervenes, and converter output capacitance and external peripherals are not directly equivalent to this sum. The workbook uses a conservative **110 uF screening assumption for known PDB/host input capacitance**, not a measured upper bound for the installed system. Fast-corner inrush is 0.316 A. Adding the 5 A constant-current example gives 5.316 A, below the 7.921 A breaker lower corner, but a converter can draw constant power and behave differently during startup.

A rectangular mixed-corner single-FET energy screen is about 1.733 J. Compare the actual VDS(t), ID(t) and starting case temperature against Infineon's SOA curves at 25 C and 125 C, including repeated retries. Do not divide stress equally between back-to-back FETs or equate avalanche energy with startup SOA. The high-drain-voltage FET can take almost all the linear stress. No startup component change is justified solely by the assumed 110 uF number; measure input/output/gate/shunt waveforms with Osiris and its intended peripherals before selecting a different C1 or retry policy.

Sources: [LTC4368 Rev. C](https://www.analog.com/media/en/technical-documentation/data-sheets/ltc4368.pdf), [ISC015N06NM5LF2](https://www.infineon.com/assets/row/public/documents/24/49/infineon-isc015n06nm5lf2-datasheet-en.pdf).

## Pack protection proposal — not installed or qualified

The earlier discussions identify the AERO SELFIE 45 A four-in-one ESC and explicitly used nominal motor/load examples; they do not provide a measured pack ESR or specific battery capacity/C rating. A four-channel ESC's 45 A rating is not its combined battery-input current. The 60 A continuous / 100 A for 30 s target remains incompatible with the selected 45 A XT60PW-F common input. The connector's momentary 60 A duration is unspecified. Software telemetry on J4 cannot measure or enforce ESC current on J3.

F2 remains SCHURTER 3-140-177, 100 A. Published breaking capacity is 600 A at 50 VDC, 1000 A at 32 VDC, 1300 A at 24 VDC, 2000 A at 16 VDC. Full 4S is **16.8 V**, so do not automatically use the 16 V rating or interpolate a rating. The datasheet's time-current tests use 22 mm wide, 210 um copper, unlike this PCB. Its 3200 A²s figure is typical melting I²t at 10x current, not a guaranteed total-clearing rating for the installed battery circuit. It is not protection for sustained overload of a 45 A connector.

For a deliberately lower-current bench/prototype harness, a concrete source-side candidate is **Littelfuse JLLN030.T, 30 A Class T**, with a matching enclosed LFT30-series holder and verified wire/terminal ampacity, installed close to the pack positive terminal **before J1**. Littelfuse publishes 160 VDC / 50 kA DC interruption for 1–30 A JLLN. This is a proposed external system component; it is not in the PCB BOM and is not installed by a PCB factory. It changes the allowable operating envelope and cannot support the previous 60/100 A goal. Check the exact holder, curve, temperature, expected motor current/inrush, harness withstand and total clearing let-through before adoption. A 30 A fuse is not an electronic 30 A limiter.

Required measured inputs: maximum pack voltage; minimum pack+lead+contact resistance over temperature and state of charge; loop inductance; wire gauge/length and insulation limits; fuse/holder temperature; maximum actual motor/prop current; clearing-time and total-I²t envelopes. Isc = V/R is only a DC screening model, not an inductive battery-fault test. Do not short a pack to measure it. Until coordinated, use a current-limited bench supply for bring-up and leave propulsion disconnected.

Sources: [SCHURTER UHS](https://www.schurter.com/en/datasheet/typ_UHS.pdf), [Littelfuse JLLN](https://www.littelfuse.com/assetdocs/jlln-datasheet?assetguid=3a7bc9bf-d932-4401-bdc7-b39f302195cf).

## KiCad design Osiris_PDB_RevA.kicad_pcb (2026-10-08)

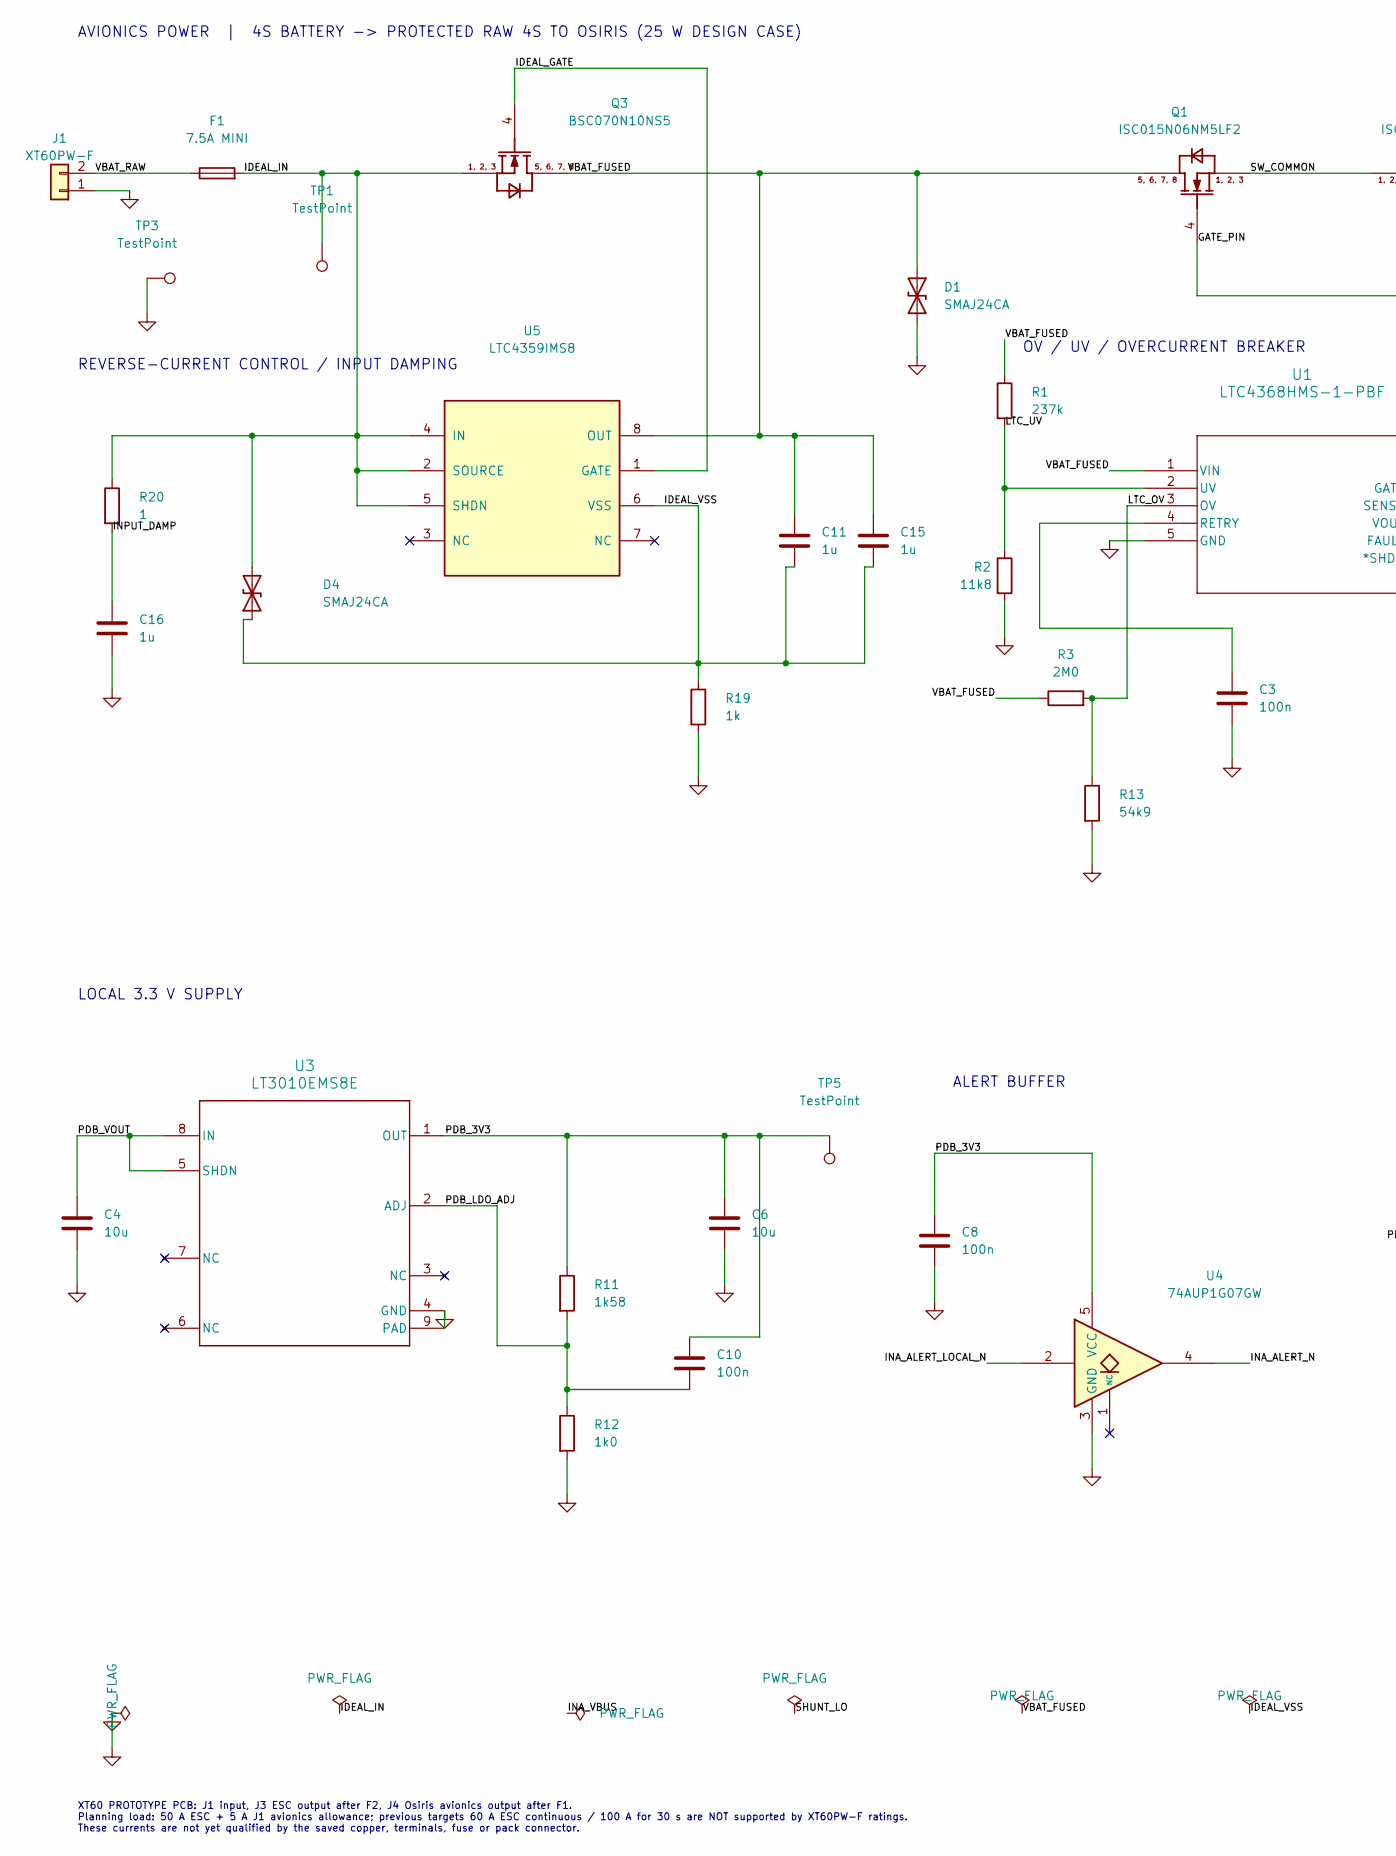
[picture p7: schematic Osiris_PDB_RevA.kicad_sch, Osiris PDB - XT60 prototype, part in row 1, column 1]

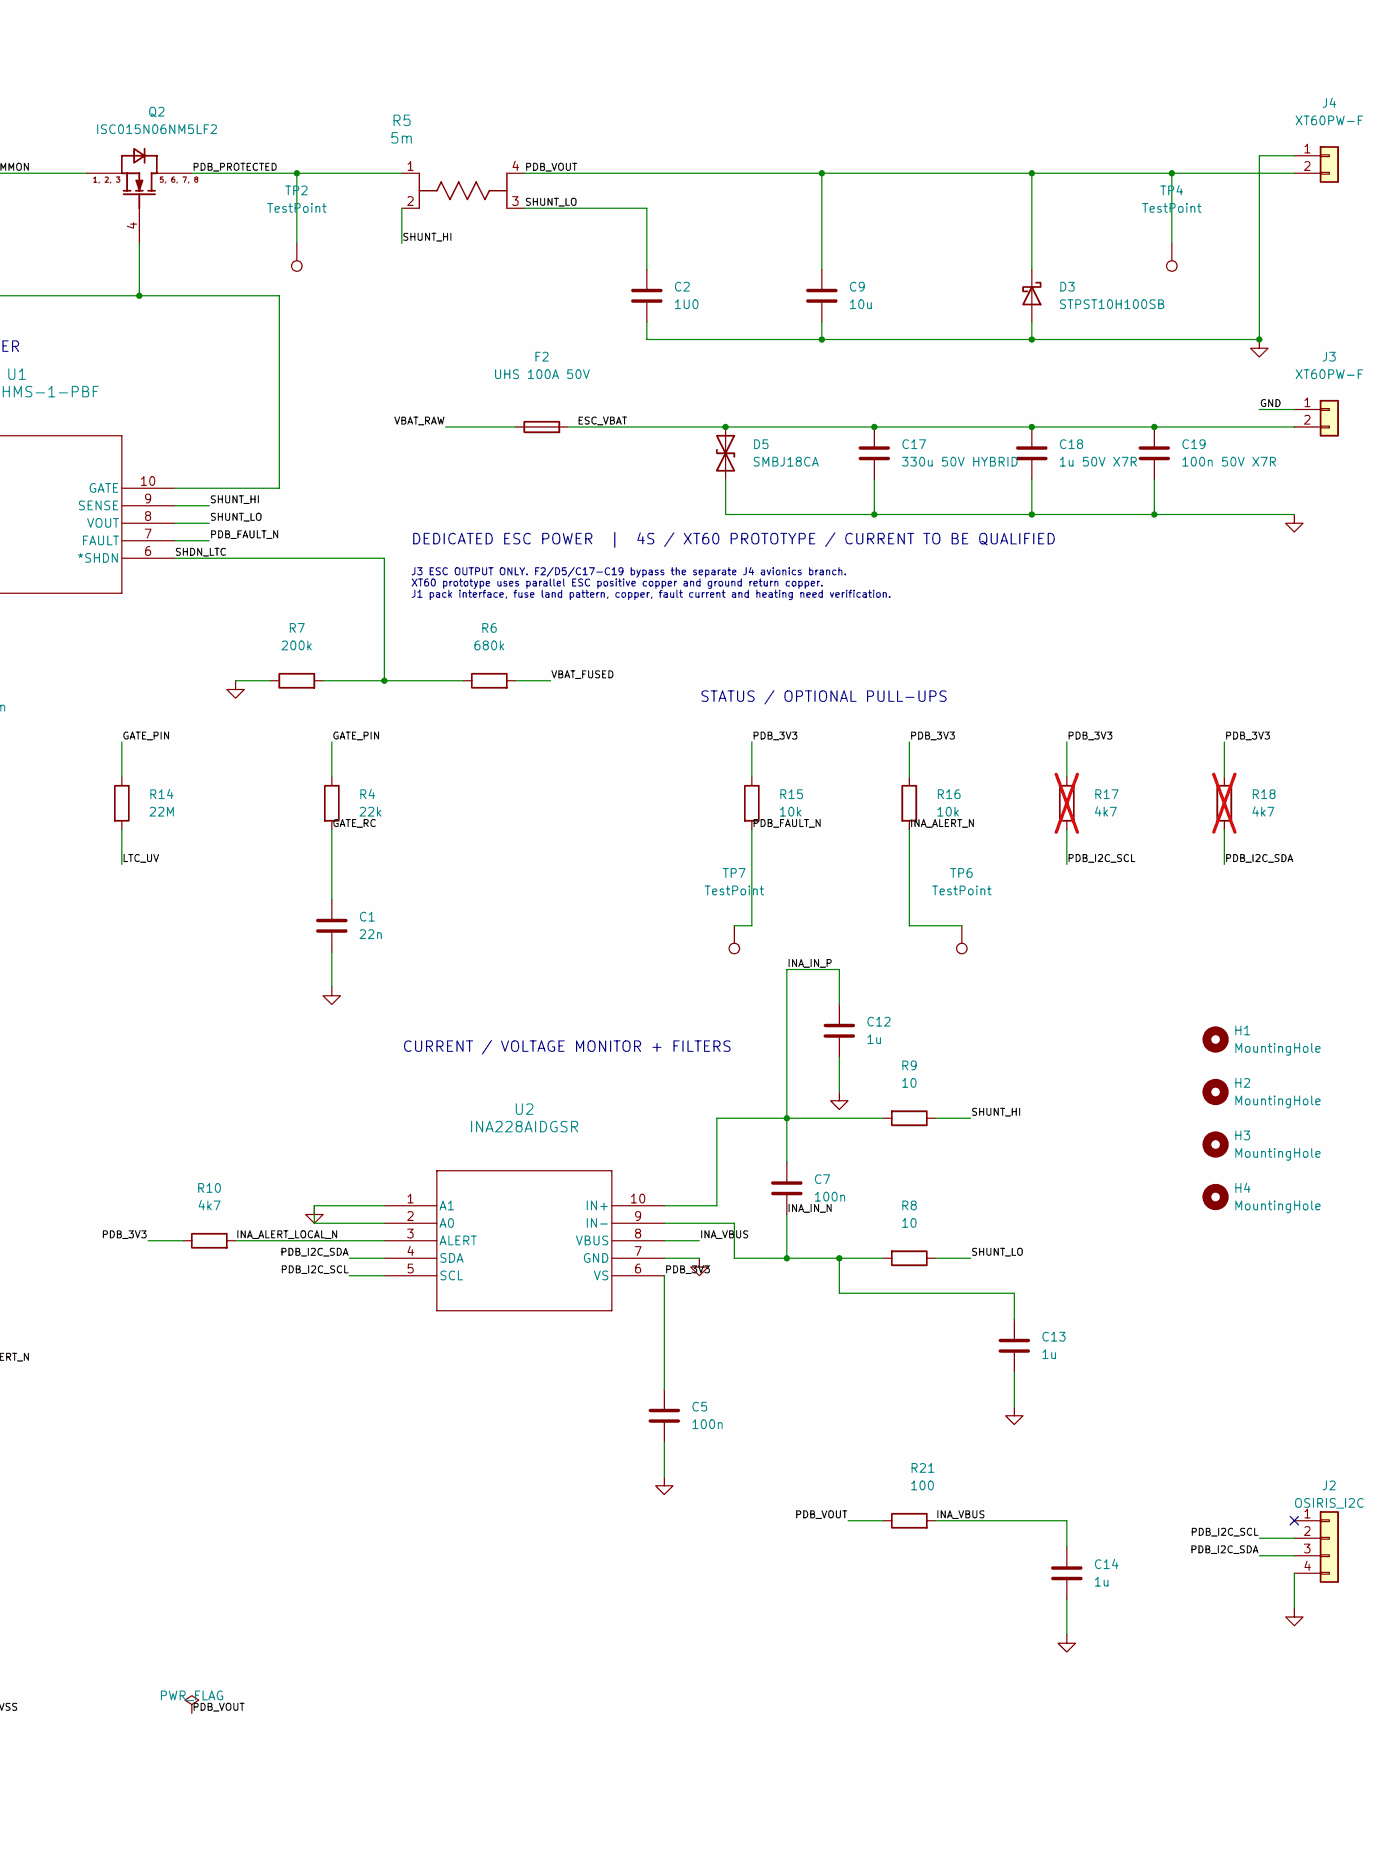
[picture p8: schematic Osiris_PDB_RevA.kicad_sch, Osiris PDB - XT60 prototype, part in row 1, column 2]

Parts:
C1: 22n; C_0805_2012Metric; MPN C2012C0G2A223J125AC
C2: 1U0; C_0805_2012Metric; MPN CC0805KKX7R9BB105
C3, C5, C8, C10: 100n; C_0603_1608Metric; MPN C0603C104K4RACTU
C4, C9: 10u; C_1206_3216Metric; MPN C3216X7R1H106K160AC
C6: 10u; C_0805_2012Metric; MPN C2012X7R1A106K125AC
C7: 100n; C_0603_1608Metric; MPN C1608X7R1H104K080AA
C11, C12, C13, C14, C15, C16: 1u; C_Rect_L7.2mm_W4.5mm_P5.00mm_JLC; MPN B32529C0105J189
C17: 330u 50V HYBRID; CP_Elec_Panasonic_G16_10x16.5; MPN EEHZL1H331P
C18: 1u 50V X7R; C_0805_2012Metric; MPN CC0805KKX7R9BB105
C19: 100n 50V X7R; C_0805_2012Metric; MPN CC0805KRX7R9BB104
D1, D4: SMAJ24CA; D_SMA; MPN SMAJ24CA
D3: STPST10H100SB; STPST10H100SB_DPAK; MPN STPST10H100SB-TR
D5: SMBJ18CA; D_SMB; MPN SMBJ18CA
F1: 7.5A MINI; Fuseholder_Blade_Mini_Keystone_3568; MPN 029707.5WXNV
F2: UHS 100A 50V; Fuse_SCHURTER_UHS_8.4x9.4mm; MPN 3-140-177
H1, H2, H3, H4: MountingHole; MountingHole_3.2mm_M3_ISO14580
J1, J3, J4: XT60PW-F; AMASS_XT60PW-F_1x02_P7.20mm_Horizontal_EdgeMounted; MPN XT60PW-F
J2: OSIRIS_I2C; JST_GH_BM04B-GHS-TBT_1x04-1MP_P1.25mm_Vertical; MPN BM04B-GHS-TBT(LF)(SN)
Q1, Q2: ISC015N06NM5LF2; ISC015N06NM5LF2_TDSON8FL; MPN ISC015N06NM5LF2ATMA1
Q3: BSC070N10NS5; BSC070N10NS5_TDSON8; MPN BSC070N10NS5ATMA1
R1: 237k; R_0805_2012Metric; Tolerance 1%; MPN RC0805FR-07237KL
R2: 11k8; R_0805_2012Metric; Tolerance 1%; MPN RC0805FR-0711K8L
R3: 2M0; R_0805_2012Metric; MPN 0805W8F2004T5E
R4: 22k; R_0805_2012Metric; Tolerance 1%; MPN 0805W8F2202T5E
R5: 5m; OH_FC4L64_OHM; MPN FC4L64R005FER
R6: 680k; R_0805_2012Metric; MPN 0805W8F6803T5E
R7: 200k; R_0805_2012Metric; MPN 0805W8F2003T5E
R8, R9: 10; R_0805_2012Metric; MPN 0805W8F100JT5E
R10: 4k7; R_0805_2012Metric; MPN 0805W8F4701T5E
R11: 1k58; R_0805_2012Metric; MPN RC0805FR-071K58L
R12: 1k0; R_0805_2012Metric; MPN 0805W8F1001T5E
R13: 54k9; R_0805_2012Metric; Tolerance 1%; MPN RC0805FR-0754K9L
R14: 22M; R_0805_2012Metric; Tolerance 1%; MPN RC0805JR-0722ML
R15, R16: 10k; R_0805_2012Metric; Tolerance 1%; MPN 0805W8F1002T5E
R17, R18: 4k7; R_0805_2012Metric; Tolerance 1%; MPN RC0805FR-074K7L; not fitted
R19: 1k; R_2512_6332Metric; MPN CRCW25121001FKEGHP
R20: 1; R_2512_6332Metric; MPN CRCW25121R00FKEGHP
R21: 100; R_0805_2012Metric; MPN 0805W8F1000T5E
TP1, TP2, TP3, TP4, TP5, TP6, TP7: TestPoint; TestPoint_Pad_D1.5mm
U1: LTC4368HMS-1-PBF; MS_10-MSOP_ADI; MPN LTC4368HMS-1#TRPBF
U2: INA228AIDGSR; VSSOP10_DGS_TEX; MPN INA228AIDGSR
U3: LT3010EMS8E; MSOP-8-1EP_3x3mm_P0.65mm_EP1.68x1.88mm; MPN LT3010EMS8E#TRPBF
U4: 74AUP1G07GW; SOT-353_SC-70-5; MPN 74AUP1G07GW,125
U5: LTC4359IMS8; MSOP-8_3x3mm_P0.65mm; MPN LTC4359IMS8#TRPBF

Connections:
/ESC_VBAT: C17.1, C18.1, C19.1, D5.1 (A1), F2.2, J3.2 (+)
/GATE_PIN: Q1.4 (GATE), Q2.4 (GATE), R4.1, R14.1, U1.10 (GATE)
/GATE_RC: C1.1, R4.2
/IDEAL_GATE: Q3.4 (GATE), U5.1 (GATE)
/IDEAL_IN: D4.2 (A2), F1.2, Q3.1 (SOURCE), Q3.2 (SOURCE), Q3.3 (SOURCE), R20.1, TP1.1 (1_1), U5.2 (SOURCE), U5.4 (IN), U5.5 (SHDN)
/IDEAL_VSS: C11.2, C15.2, D4.1 (A1), R19.1, U5.6 (VSS)
/INA_ALERT_LOCAL_N: R10.2, U2.3 (ALERT), U4.2
/INA_ALERT_N: R16.2, TP6.1 (1_1), U4.4
/INA_IN_N: C7.2, C13.1, R8.2, U2.9 (IN-)
/INA_IN_P: C7.1, C12.1, R9.2, U2.10 (IN+)
/INA_VBUS: C14.1, R21.2, U2.8 (VBUS)
/INPUT_DAMP: C16.1, R20.2
/LTC_OV: R3.2, R13.1, U1.3 (OV)
/LTC_UV: R1.2, R2.1, R14.2, U1.2 (UV)
/PDB_3V3: C5.1, C6.2, C8.2, C10.1, R10.1, R11.1, R15.1, R16.1, R17.1, R18.1, TP5.1 (1_1), U2.6 (VS), U3.1 (OUT), U4.5 (VCC)
/PDB_FAULT_N: R15.2, TP7.1 (1_1), U1.7 (FAULT)
/PDB_I2C_SCL: J2.2, R17.2, U2.5 (SCL)
/PDB_I2C_SDA: J2.3, R18.2, U2.4 (SDA)
/PDB_LDO_ADJ: C10.2, R11.2, R12.1, U3.2 (ADJ)
/PDB_PROTECTED: Q2.5 (DRAIN), Q2.6 (DRAIN), Q2.7 (DRAIN), Q2.8 (DRAIN), R5.1, TP2.1 (1_1)
/PDB_VOUT: C4.2, C9.1, D3.1 (K), J4.2 (+), R5.4, R21.1, TP4.1 (1_1), U3.5 (SHDN), U3.8 (IN)
/SHDN_LTC: R6.1, R7.2, U1.6 (*SHDN)
/SHUNT_HI: R5.2, R9.1, U1.9 (SENSE)
/SHUNT_LO: C2.1, R5.3, R8.1, U1.8 (VOUT)
/SW_COMMON: Q1.1 (SOURCE), Q1.2 (SOURCE), Q1.3 (SOURCE), Q2.1 (SOURCE), Q2.2 (SOURCE), Q2.3 (SOURCE)
/VBAT_FUSED: C11.1, C15.1, D1.1 (A1), Q1.5 (DRAIN), Q1.6 (DRAIN), Q1.7 (DRAIN), Q1.8 (DRAIN), Q3.5 (DRAIN), Q3.6 (DRAIN), Q3.7 (DRAIN), Q3.8 (DRAIN), R1.1, R3.1, R6.2, U1.1 (VIN), U5.8 (OUT)
/VBAT_RAW: F1.1, F2.1, J1.2 (+)
GND: C1.2, C2.2, C3.2, C4.1, C5.2, C6.1, C8.1, C9.2, C12.2, C13.2, C14.2, C16.2, C17.2, C18.2, C19.2, D1.2 (A2), D3.2 (A), D5.2 (A2), J1.1 (-), J2.4, J3.1 (-), J4.1 (-), R2.2, R7.1, R12.2, R13.2, R19.2, TP3.1 (1_1), U1.5 (GND), U2.1 (A1), U2.2 (A0), U2.7 (GND), U3.4 (GND), U3.9 (PAD), U4.3 (GND)
unnamed: C3.1, U1.4 (RETRY)

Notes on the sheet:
STATUS / OPTIONAL PULL-UPS
J3 ESC OUTPUT ONLY. F2/D5/C17-C19 bypass the separate J4 avionics branch. XT60 prototype uses parallel ESC positive copper and ground return copper. J1 pack interface, fuse land pattern, copper, fault current and heating need verification.
ALERT BUFFER
AVIONICS POWER | 4S BATTERY -> PROTECTED RAW 4S TO OSIRIS (25 W DESIGN CASE)
LOCAL 3.3 V SUPPLY
XT60 PROTOTYPE PCB: J1 input, J3 ESC output after F2, J4 Osiris avionics output after F1. Planning load: 50 A ESC + 5 A J1 avionics allowance; previous targets 60 A ESC continuous / 100 A for 30 s are NOT supported by XT60PW-F ratings. These currents are not yet qualified by the saved copper, termi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
DEDICATED ESC POWER | 4S / XT60 PROTOTYPE / CURRENT TO BE QUALIFIED
OV / UV / OVERCURRENT BREAKER
CURRENT / VOLTAGE MONITOR + FILTERS
REVERSE-CURRENT CONTROL / INPUT DAMPING

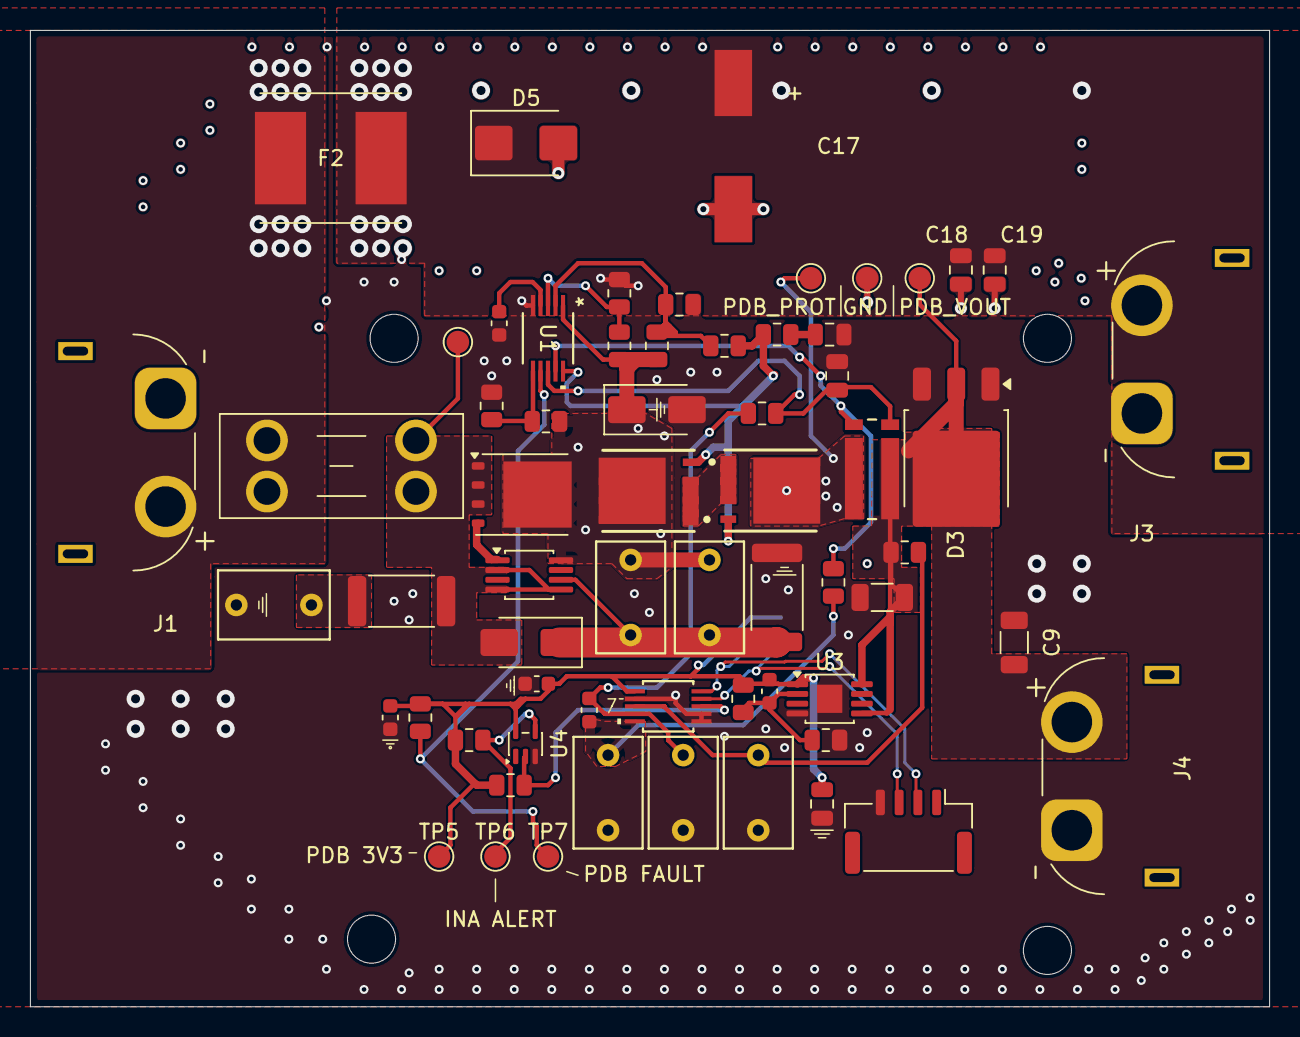
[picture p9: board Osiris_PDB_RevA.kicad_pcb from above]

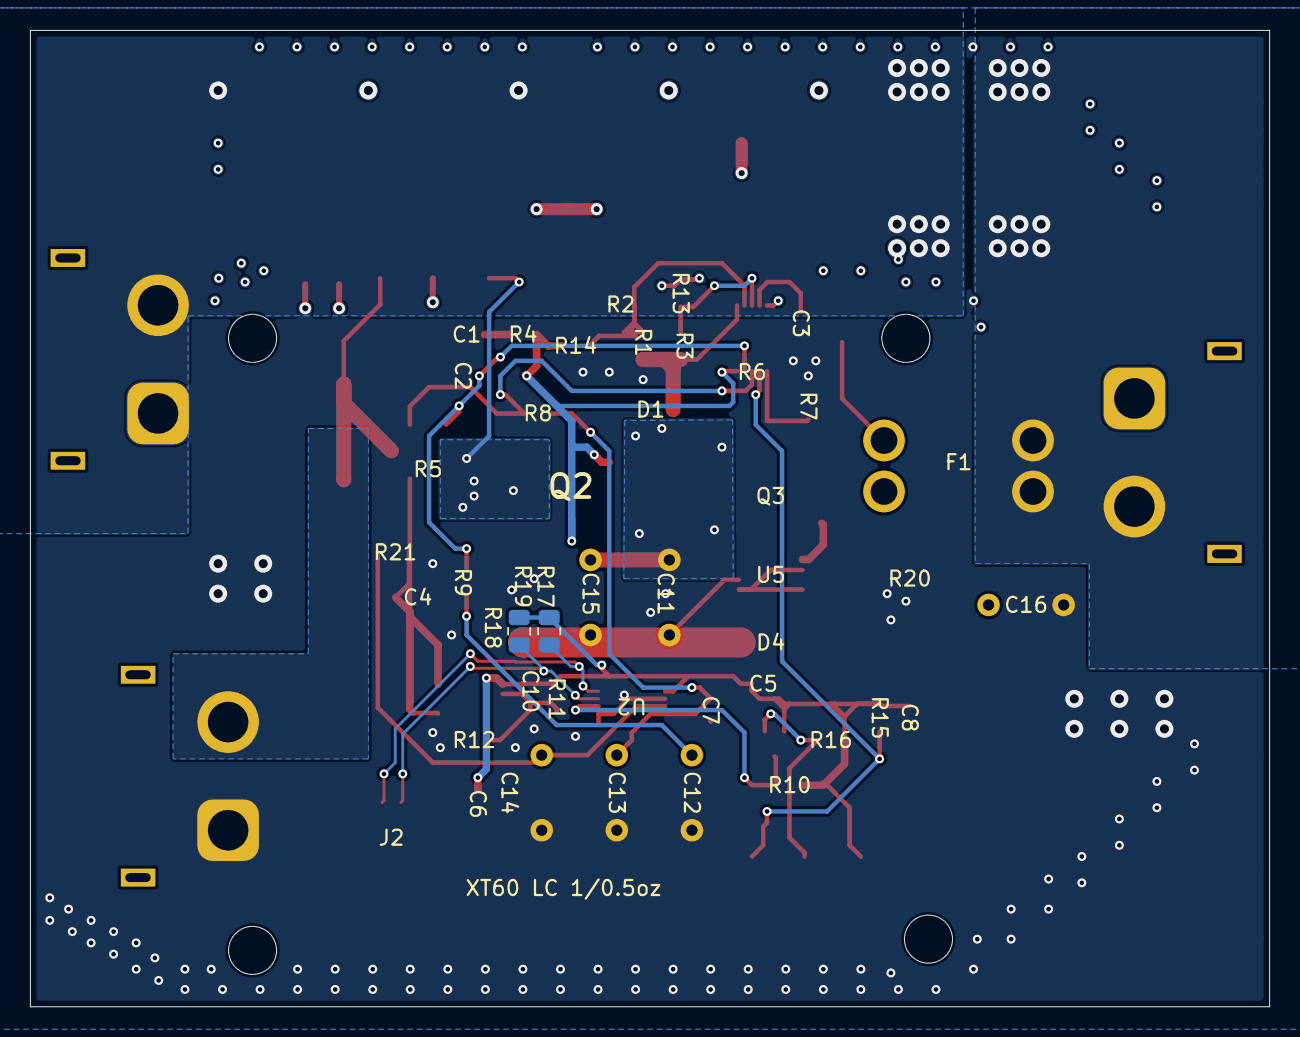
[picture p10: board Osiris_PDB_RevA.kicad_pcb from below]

Board: 4 copper layers, 82.5 x 65.0 mm, 69 parts (2 on the bottom side), 29 nets.

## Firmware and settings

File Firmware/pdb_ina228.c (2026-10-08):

#include "pdb_ina228.h"
#include <math.h>
#define PDB_ADDRESS 0x40u
#define SHUNT_CAL 4096u
#define ADC_CONFIG 0xFB6Au /* continuous V/I/T, 1052 us each, 16 averages */
static bool read16(pdb_ina228 *d,uint8_t reg,uint16_t *v){
 uint8_t b[2];if(!d->read(d->context,PDB_ADDRESS,reg,b,2))return false;
 *v=(uint16_t)(((uint16_t)b[0]<<8)|b[1]);return true;
}
static bool write16(pdb_ina228 *d,uint8_t reg,uint16_t v){
 uint8_t b[2]={(uint8_t)(v>>8),(uint8_t)v};return d->write(d->context,PDB_ADDRESS,reg,b,2);
}
static bool read20(pdb_ina228 *d,uint8_t reg,bool sign,int32_t *v){
 uint8_t b[3];uint32_t raw;
 if(!d->read(d->context,PDB_ADDRESS,reg,b,3))return false;
 raw=((uint32_t)b[0]<<16)|((uint32_t)b[1]<<8)|b[2];raw>>=4;
 *v=(sign && (raw&0x80000u))?(int32_t)raw-1048576:(int32_t)raw;return true;
}
static pdb_status configuration(pdb_ina228 *d){
 uint16_t c,a,s;
 if(!read16(d,0,&c)||!read16(d,1,&a)||!read16(d,2,&s)){d->configured=false;return PDB_IO_ERROR;}
 if(c!=0||a!=ADC_CONFIG||s!=SHUNT_CAL){d->configured=false;return PDB_CONFIG_LOST;}
 return PDB_OK;
}
double pdb_ina228_current_lsb(const pdb_ina228 *d){
 return d && isfinite(d->shunt_ohms) && d->shunt_ohms>0 ? SHUNT_CAL/(13107200000.0*d->shunt_ohms):NAN;
}
pdb_status pdb_ina228_init(pdb_ina228 *d){
 uint16_t manufacturer,id;
 if(!d||!d->read||!d->write||!isfinite(d->shunt_ohms)||d->shunt_ohms<=0)return PDB_BAD_ARGUMENT;
 d->configured=false;
 if(!read16(d,0x3E,&manufacturer)||!read16(d,0x3F,&id))return PDB_IO_ERROR;
 if(manufacturer!=0x5449u||(id&0xFFF0u)!=0x2280u)return PDB_WRONG_DEVICE;
 /* Stop conversions while programming; never use ADCRANGE=1 on this board. */
 if(!write16(d,1,0)||!write16(d,0,0)||!write16(d,2,SHUNT_CAL)||!write16(d,1,ADC_CONFIG))return PDB_IO_ERROR;
 {pdb_status status=configuration(d);if(status!=PDB_OK)return status;}
 d->configured=true;return PDB_OK;
}
pdb_status pdb_ina228_sample(pdb_ina228 *d,pdb_sample *s){
 uint16_t flags;int32_t current,bus,shunt;pdb_status status;
 if(!s)return PDB_BAD_ARGUMENT;
 s->valid=false;s->current_a=NAN;s->bus_v=NAN;s->shunt_v=NAN;s->diagnostic=0;
 if(!d||!d->read||!d->configured)return PDB_CONFIG_LOST;
 if(!isfinite(d->shunt_ohms)||d->shunt_ohms<=0){d->configured=false;return PDB_BAD_ARGUMENT;}
 status=configuration(d);if(status!=PDB_OK)return status;
 if(!read16(d,0x0B,&flags))return PDB_IO_ERROR;
 s->diagnostic=flags;
 if(!(flags&1u)||(flags&0x200u))return PDB_SENSOR_FAULT; /* MEMSTAT / MATHOF */
 if(!(flags&2u))return PDB_NOT_READY;
 if(!read20(d,7,true,&current)||!read20(d,5,false,&bus)||!read20(d,4,true,&shunt))return PDB_IO_ERROR;
 /* Reject clipping rather than silently presenting it as a real current. */
 if(current==524287||current==-524288||shunt==524287||shunt==-524288||bus==1048575)return PDB_SENSOR_FAULT;
 status=configuration(d);if(status!=PDB_OK)return status;
 s->current_a=current*pdb_ina228_current_lsb(d);s->bus_v=bus*0.0001953125;s->shunt_v=shunt*0.0000003125;s->valid=true;return PDB_OK;
}

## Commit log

2026-09-08 Initial portable Osiris PDB Rev A project
    [BOM.csv, Osiris_PDB_RevA.kicad_pcb, Osiris_PDB_RevA.kicad_sch]
2026-09-08 FIX
    FIX
    [Osiris_PDB_RevA.kicad_sch, Osiris_PDB_RevA.sch]
2026-09-13 Consolidate Rev A schematic, component libraries and readiness review
    [BOM.csv, BOM_purchasing.csv, Osiris_PDB_RevA.kicad_pcb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]
2026-09-13 Freeze A-P1 procurement baseline and feeder planning package
    [BOM.csv, BOM_purchasing.csv, Osiris_PDB_RevA.kicad_sch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]
2026-09-13 Document joint PDB and Osiris Rev B completion milestones
2026-09-14 Add general lab procurement workbook with quantities and links
    [Lab-Procurement.xlsx]
2026-09-15 Add Osiris procurement quantities pricing and supply review
    [Lab-Procurement.xlsx]
2026-09-17 update 9/17/26
    [BOM.csv, BOM_purchasing.csv, Osiris_PDB_RevA.kicad_pcb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]
2026-09-23 routing main power path 25%
    [Osiris_PDB_RevA.kicad_pcb, Osiris_PDB_RevA.kicad_sch]
2026-09-28 Save current PDB schematic and layout updates
    [Osiris_PDB_RevA.kicad_pcb, Osiris_PDB_RevA.kicad_sch]
2026-09-28 Review PDB manufacturing readiness and correct board checks
    [Osiris_PDB_RevA.kicad_pcb, schematic-bom.csv]
2026-09-29 Resolve PDB CAD checks and prepare assembly handoff drafts
    [Osiris_PDB_RevA.kicad_pcb, Osiris_PDB_RevA.kicad_sch, assembly-bom-draft.csv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]
2026-09-29 Document shared PDB outputs and diode function
2026-09-29 Record 25 W Jetson load in PDB release review
2026-09-29 Flag shared ESC and avionics output as release blocker
2026-09-29 Document required on-board ESC power branch
2026-09-29 Set provisional high-current ESC branch design basis
2026-09-29 added power path for esc on schematic
    [Osiris_PDB_RevA.kicad_sch]
2026-09-29 Route compact three-XT60 PDB candidate
    [Osiris_PDB_RevA.kicad_pcb, Osiris_PDB_RevA.kicad_sch]
2026-09-29 Document shorter ESC power-lane placement concept
2026-09-29 Document AERO SELFIE ESC current assumptions
2026-09-29 Study single-battery Phoenix PDB power path
    [Osiris_PDB_RevA.kicad_pcb]
2026-09-30 Promote latest PDB revision and remove generated artifacts
    [BOM.csv, BOM_purchasing.csv, Lab-Procurement.xlsx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]
2026-10-01 Restore compact PDB layout shown in reference image
    [Osiris_PDB_RevA.kicad_pcb, Osiris_PDB_RevA.kicad_sch]
2026-10-01 Update PDB design and purchasing deliverables
    [Osiris_PDB_RevA.kicad_pcb, Osiris_PDB_RevA.kicad_sch, Osiris_PDB_RevA_Updated_Purchasing_Cost.xlsx]
2026-10-02 fixed grnd fault
    [Osiris_PDB_RevA.kicad_pcb]
2026-10-02 fixes 10.2.26
    [Osiris_PDB_RevA.kicad_pcb, Osiris_PDB_RevA.kicad_sch]
2026-10-02 Prepare PDB Rev A JLCPCB prototype manufacturing package
    [Do_Not_Populate.csv, Engineering_BOM.csv, JLCPCB_BOM.csv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]
2026-10-05 Add widened-copper 1 oz / 0.5 oz PDB test prototype
    [Do_Not_Populate.csv, JLCPCB_BOM.csv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]
2026-10-08 Update REV1.1 XT60 PDB and publish clean JLCPCB outputs
    [BOM.csv, Osiris_PDB_REV1.1_XT60_Procurement_PnP.xlsx, Osiris_PDB_RevA.kicad_pcb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]
2026-10-08 Use stocked passive alternatives and refresh REV1.1 procurement outputs
    [BOM.csv, Osiris_PDB_REV1.1_XT60_Procurement_PnP.xlsx, Osiris_PDB_RevA.kicad_pcb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]
2026-10-08 Clarify PnP extra part quantities and tape purchasing guidance
    [Osiris_PDB_REV1.1_XT60_Procurement_PnP.xlsx]
2026-10-15 Update INA238 telemetry, ESC capacitor bank and procurement outputs
2026-10-15 Update JLC sourcing BOM and five-board procurement workbooks
2026-10-23 Track procurement replacements and verify school purchasing workbook
